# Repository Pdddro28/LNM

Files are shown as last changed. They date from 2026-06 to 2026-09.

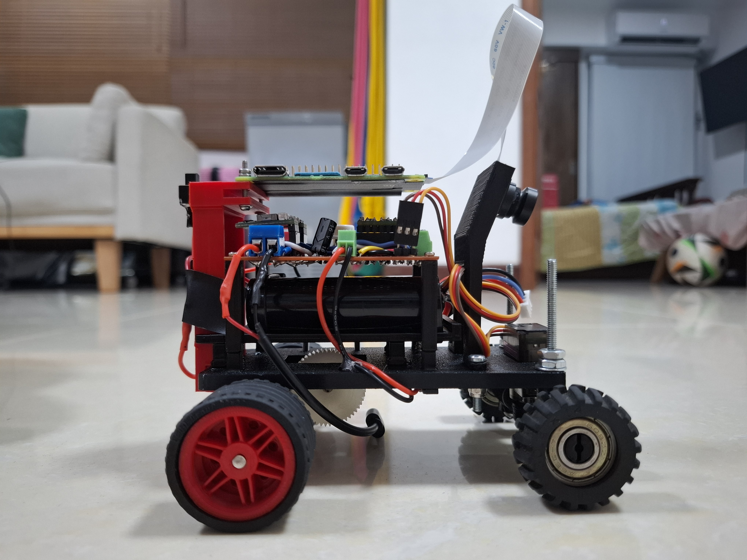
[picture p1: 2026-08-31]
v-photos/Right-view.jpg

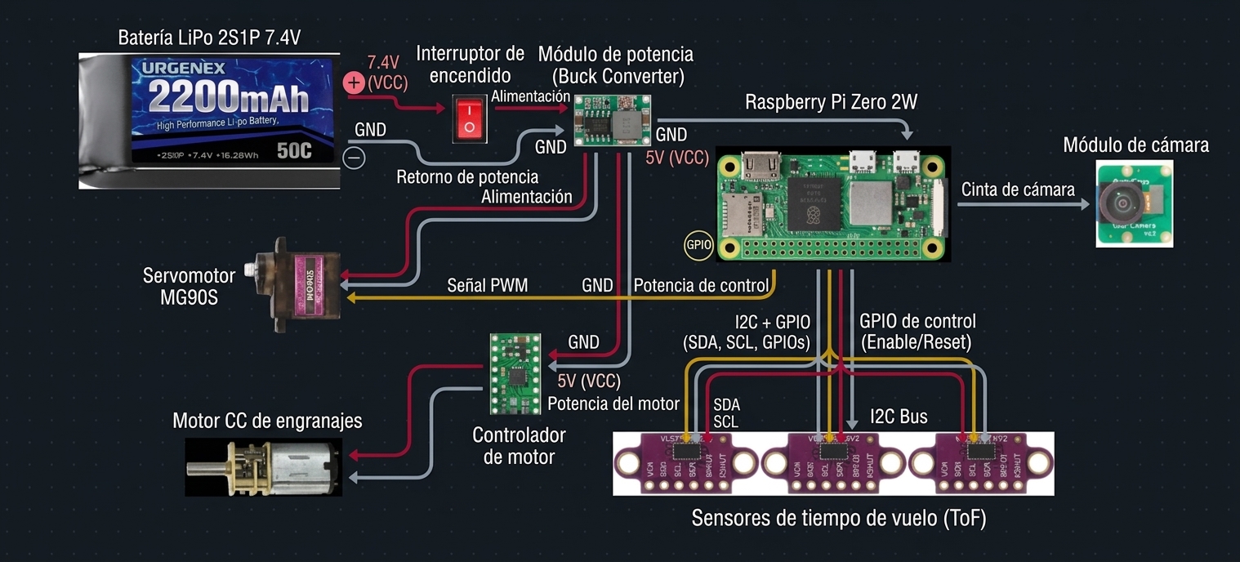
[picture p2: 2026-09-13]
schemes/diagrama_de_cableado.png

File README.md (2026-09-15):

**If you want to see this repository in English, [click here](https://github.com/Pdddro28/K-O-M-R-A-D/blob/main/README_EN.md)**

``` Para mejor visualización, se recomienda ver el repositorio en la computadora ```

# WRO 2026 Future Engineers – LNM

<div align="center">
	
<img width="1000" height="600" alt="WhatsApp Image 2026-06-19 at 11 51 57 PM" src="https://github.com/user-attachments/assets/cee364df-eeba-4338-8f2a-14949adb755b" />

</div>

## **Índice**

1. **[Introducción](#1-introduccion)**
   - 1.1. **[Miembros y Coach](#11-miembros-y-coach)**
      - 1.1.1. **[David Wang](#111-David)**
      - 1.1.2. **[Pedro Catámo](#112-Pedro)**
2. **[Proyectos anteriores](#2-proyectos-anteriores)**
3. **[Diseño y mobilidad](#3-diseño-y-mobilidad)**
   - 3.1. **[Fotos del vehiculo](#31-fotos-del-vehiculo)**
   - 3.2. **[Especificaciones del vehiculo](#32-especificaciones-del-vehiculo)**
   - 3.3. **[Mecanismo ackermann](#33-mecanismo-ackermann)**
   - 3.4. **[Tracción trasera](#34-tracción-trasera)**
   - 3.5. **[Partes 3D, proceso de desarollo y recomendaciones](#35-partes-3d-proceso-de-desarollo-y-recomendaciones)**
4. **[Componentes](#4-componentes)**
   - 4.1. **[Disposicion y justificacion](#41-disposicion-y-justificacion)**
5. **[Presupuesto de energia](#5-presupuesto-de-energia)**
   - 5.1. **[Diagrama de cableado](#51-diagrama-de-cableado)**
6. **[Software](#6-software)**
   - 6.1. **[Herramientas de apoyo](#61-herramientas-de-apoyo)**
   - 6.2. **[Intalación en shell](#62-instalacion-en-shell)**
   - 6.3. **[Compilación y ejecución de archivos(codigos del carro)](#63-compilacion-y-ejecucion)**
   - 6.4. **[Abreviaciones con bash](#64-abreviaciones-con-bash)**
   - 6.5. **[Megapi controller(Deprecated)](#65-megapi-controllerdeprecated)**
   - 6.6. **[Challenge Overview](#66-challenge-overview)**
      - 6.6.1 **[Open Challenge](#661-open-challenge)**
      - 6.6.2 **[Obstacle Challenge](#662-obstacle-challenge)**
      - 6.6.3. **[Estrategia en Ronda Abierta](#663-ronda-abierta-estrategia)**
      - 6.6.4. **[Estrategia en Ronda de Obstáculos](#664-ronda-de-obstaculos-estrategia)**
7. **[Problemas y soluciones durante el desarollo](#7-problemas-y-soluciones-durante-el-desarollo)**
8. **[Licencia y réplica](#8-licencia-y-replicacion)**

---

## 1. Introducción 

Bienvenidos al repositorio de GitHub del **Equipo LNM**, anteriormente conocido como Ars Machina, que compite en la categoría **World Robot Olympiad™ (WRO®) Future Engineers 2026**. Nuestro equipo ha diseñado un vehículo autónomo compacto e innovador para hacer frente a los retos dinámicos de la competición WRO 2026.

Esta es la estructura general de carpetas de nuestro repositorio:

<div align="center">
	
| Carpeta | Contenido técnico | Documentación detallada |
|---|---|---|
| **models** | **Diseños 3D**<br>• Piezas del carro| [Explora los modelos 3D](models/README.md) |
| **schemes** | **Sistemas eléctricos**<br>• Diagramas de cableado<br>• Gestión de la alimentación<br>• Esquemas de componentes| [Explora la documentación de esquemas y cableado](schemes/README.md) |
| **src** | **Algoritmos de software**<br>• Lógica de navegación<br>• Fusión de sensores<br>• Sistemas de control | [Explora la documentación de software y algoritmos](src/README.md) |
| **t-photos** | **Documentación del equipo**<br>• Perfiles de los miembros | [Explora la documentación de fotos del equipo](t-photos/README.md) |
| **v-photos** | **Documentación del vehículo**<br>• Vistas desde múltiples ángulos | [Explora la documentación de fotos del vehículo](v-photos/README.md) |
| **video** | **Validación del rendimiento**<br>• Demostraciones del desafío<br>• Pruebas de ingeniería | [Explora la documentación de los vídeos de rendimiento](video/README.md) |

</div>

### 1.1. Miembros y Coach 

<div align="center">
	
<img width="1280" height="720" alt="Team_pic (1)" src="https://github.com/user-attachments/assets/156c3c29-799e-44e6-a7f0-629da61873b8" />

</div>

<div align="center">

| **Miembro** | **Miembro** | **Coach** |
| :---: | :---: | :---: |
| 👤 **David Wang** | 👤 **Pedro Catamo** | 👤 **Jesús Alcalá** |
| 📅 **Nacido en:** 04/01/2011 (15 años)<br>🏫 **Estudio:** 4º año en la U.E.C. Eduardo Blanco<br>📧 **Gmail:** [davidwangwu104@gmail.com](mailto:davidwangwu104@gmail.com) | 📅 **Nacido en:** 28/01/2009 (17 años)<br>🏫 **Estudio:** Graduado en la U.E.C. Colegio Eduado Blanco<br>📧 **Gmail:** [pedrocatamo.2009@gmail.com](mailto:pedrocatamo.2009@gmail.com) | 📅 **Nacido en:** 18/11/2005 (21 años) <br> 🏫 **Estudio:** Ingenieria en computación & Ingenieria informática <br> 📧 **Gmail:** [Jdam50002@gmail.com](mailto:Jdam50002@gmail.com) |

</div>

---

#### 1.1.1. David Wang 

**Rol: Programación y Lógica Autónoma, Integrador de Sistemas y  Diseñador 3D**

<div align="center">

<img width="400" height="700" alt="David" src="https://github.com/user-attachments/assets/f19589c0-22ea-44fb-ba63-21a8cb10d5f8" />

</div>

* **Programación y Lógica Autónoma:** Me encargo del desarrollo del código en la placa pprincipal, la lógica de control del vehículo y la programación del sistema de visión por computadora.

* **Integración de Sistemas:** Me aseguro de que la información de la cámara se traduzca correctamente en movimientos del vehículo de forma fluida.

* **Diseñador 3D:** Trabajo en la conceptualización y modelado CAD del chasis y las piezas junto al mentor del área técnica, adaptando la estructura según las necesidades del espacio que requiere la electrónica.

#### 1.1.2. Pedro Catámo 

**Rol: Ensamblaje Mecánico y Mantenimiento, Ingeniería de Pruebas y Telemetría y Redacción y Gestión del Reporte Técnico**

* **Ensamblaje Mecánico y Mantenimiento:** Me encargo del montaje físico del carro, el ajuste de tornillería, la calibración de componentes con herramientas de precisión y la revisión del estado general del vehículo para evitar fallos físicos.

* **Ingeniería de Pruebas y Telemetría:** Registro los tiempos en pista, mide el rendimiento del carro en cada intento y anota qué ajustes físicos o de parámetros generan mejoras o fallos.

* **Redacción y Gestión del Reporte Técnico:** Responsable principal de estructurar y maquetar el documento del proyecto que se entrega a los jueces, recopilando la información del código, el diseño y las pruebas.

#### 1.1.3. Jesús Alcalá 

**Rol: Mentor de Programación y Lógica, Mentor de Diseño y Estructura y Mentor de Gestión y Reglamento**

<div align="center">

<img width="500" height="700" alt="1000281781" src="https://github.com/user-attachments/assets/f77cb86f-cff0-4f8c-8ea1-c10f3c5291b0" />

</div>

* **Mentor de Programación y Lógica:** Me encargo de guiarlos en la arquitectura del código, la lógica de navegación autónoma y el procesamiento de imágenes. Los oriento en la resolución de errores lógicos y en la optimización del programa para garantizar un rendimiento estable en pista.

* **Mentor de Diseño y Estructura:** Me encargo de guiarlos en la concepción física del vehículo, enseñándoles técnicas de diseño CAD y optimización de piezas para lograr un chasis resistente y funcional.

* **Mentor de Gestión y Reglamento:** Encargado de verificar el cumplimiento estricto del reglamento de la WRO, asesorarlos en la estructuración de la documentación técnica y orientarlos en las decisiones generales del proyecto para asegurar un desarrollo ordenado.

---

## 2. Proyectos anteriores 

<div align="center">
	
| Foto | Nombre | Descripción |
|---|---|---|
| <img width="5000" height="5000" alt="Captura de pantalla 2026-06-17 185504" src="https://github.com/user-attachments/assets/36166165-a542-42d6-a771-41a60693a399" /> | **Cyber Cooper** | En 2023 teníamos pensado diseñar el coche desde cero, modelando e imprimiendo nuestras propias piezas en 3D, incluidos el chasis y el sistema de dirección. Aunque al principio parecía una buena idea, a medida que avanzábamos empezamos a encontrarnos con un problema tras otro, y nos dimos cuenta de que nuestro diseño actual nos acarrearía más dificultades. Al final, hicimos todo lo que pudimos dentro de las limitaciones de tiempo que teníamos. |
| <img width="5000" height="5000" alt="front2" src="https://github.com/user-attachments/assets/ce130237-cc0b-4aa9-a620-0aea287408c2" /> | **Cooper** | En 2024 desarrollamos un chasis con piezas 3D estructurado en dos niveles. El nivel inferior albergaba los sensores y la electrónica de bajo nivel, mientras que el superior sostenía las baterías y la Raspberry Pi 3 para optimizar el espacio. Aunque logramos un gran avance estético y funcional, sufrimos lecciones duras en pista: el peso excesivo provocó la flexión de los acoples en la transmisión trasera, lo cual, a su vez, generó problemas severos de fricción mecánica entre las piezas impresas en 3D. |
| <img width="5000" height="5000" alt="front" src="https://github.com/user-attachments/assets/804b3d7f-3500-4351-a917-ccf781029804" /> | **Halbi** | En 2025 teniendo en cuenta los recursos de los que disponíamos en ese momento, nuestra idea principal era rediseñar el Cybercooper, modificando la base y la estrategia existentes y utilizando mejores componentes electrónicos; empezamos a imprimir las nuevas piezas con material blanco y a pensar en mejores formas de montar el sistema de dirección del coche. Al final, decidimos utilizar una base prefabricada para el chasis; la razón principal fue ahorrar tiempo (y dolores de cabeza) con el diseño mecánico, lo que nos permitía dedicar más tiempo a la electrónica y la programación. |
| <img width="5000" height="5000" alt="WhatsApp Image 2026-06-18 at 7 39 40 PM" src="https://github.com/user-attachments/assets/ca9f62ff-7b8b-452a-97de-95ebf12dc0ef" /> | **The Fridge** | En 2025 a diferencia de los modelos anteriores que pertenecían a nuestro coach, "The Fridge" fue un diseño construido enteramente por nosotros. Aquí dimos el salto a la geometría Ackermann e imprimimos la gran mayoría de las piezas en 3D. A nivel motriz, usamos un motor DC con un engranaje acoplado para traccionar ambas ruedas. Físicamente le instalamos 3 sensores ultrasónicos, una Raspberry Pi 4 y un giroscopio MPU6050, pero por falta de tiempo y severos problemas de configuración, la Raspberry y el IMU quedaron como peso muerto y terminamos controlando todo únicamente desde la MegaPi. Sufrimos muchísimo: las piezas de la dirección impresas en 3D se rompían constantemente por el estrés, y programar la navegación autónoma en Arduino dependiendo de puros rebotes ultrasónicos fue casi imposible. Siendo sinceros, terminó siendo el peor proyecto de los tres. |
| <img width="5000" height="5000" alt="604735892-f1dc12a1-dbfc-46f3-9a21-a679aa1aa3db" src="https://github.com/user-attachments/assets/2101e66c-5b43-4e2d-938d-b143c6c9f9ed" /> | **Halbi The Green** | Este es el primer modelo que hemos fabricamos como LNM, siendo el carro con el cual competimos en las primeras regionales de WRO Venezuela 2026, este lograba realizar la ronda abierta de manera perfecta en un tiempo de alrededor de 20seg pero a la hora de la ronda de obstaculos este se veia frenado por diversas limitaciones tales como; Su tamaño debido a que el ancho de este le dificultaba atravesar los obstaculos de manera precisa, limitaciones del sistema de direccion el cual no podia realizar giros cerrados, otra de las dificultades que se presentaron fue que algunos de los cables del robot y sensores de los laterales tumbaban los obstaculos de manera ocacional, en resumen el principal problema de Halbi The Green fue su tamaño y su incapacidad de hacer giros cerrados. |

</div>

---

## 3. Diseño y mobilidad 

A continuación se detalla la construcción y funcionamiento dinámico de nuestro robot **Halbi The Green**:

### 3.1. Fotos del vehiculo 

<div align="center">

| | **Diferentes ángulos del carro** | |
|---|---|---|
| **Superior** | **Derecha** | **Izquierda** |
| <img width="2000" height="2000" alt="Upper-view" src="https://github.com/user-attachments/assets/2a0562c0-60e4-4d0a-a93d-6cc70a388efa" /> | <img width="2000" height="2000" alt="Right-view" src="https://github.com/user-attachments/assets/336adf6b-3f85-432b-8a5c-26227200b8f9" /> | <img width="2000" height="2000" alt="Left-view" src="https://github.com/user-attachments/assets/d6df94f0-d30b-46f6-812e-c9d6f7930e63" /> |
|**Frontal** | **Trasera** | **Inferior** |
| <img width="2000" height="2000" alt="Front-view" src="https://github.com/user-attachments/assets/ef03746f-1543-4490-8521-824d5e7d0d57" /> | <img width="2000" height="2000" alt="Back-view" src="https://github.com/user-attachments/assets/150ab54f-12d3-4e58-a0bc-a9be14865f2c" /> | <img width="2000" height="2000" alt="Bottom-view" src="https://github.com/user-attachments/assets/a253c009-53f8-4fcc-a485-942bfddd27fd" /> |

</div>

### 3.2. Especificaciones del vehiculo 

* **Dimensiones totales:** 14 cm (largo) × 12 cm (ancho) × 10.3 cm (alto).
* **Peso del carro:** aproximadamente 346g.
* **Sistema de tracción:** Tracción Trasera Mecánica Bifásica.
* **Sistema de dirección:** Geometría Ackermann.

### 3.3. Mecanismo ackermann 

El vehículo utiliza una geometría precisa basada en el **Principio de Dirección Ackermann** para conquistar curvas cerradas con cero deslizamiento lateral y un desgaste mínimo de los neumáticos.

* **La Física Detrás del Principio:** Cuando un vehículo entra en una curva, la rueda delantera interior sigue un radio concéntrico más cerrado y pequeño que la rueda exterior. Si ambas ruedas giraran exactamente al mismo ángulo, los neumáticos lucharían entre sí, provocando que el neumático exterior se arrastre, pierda agarre mecánico e introduzca vibraciones estructurales severas que arruinarían el seguimiento visual de los carriles. Para resolver esto, la geometría mecánica obliga a la rueda interior a pivotar a un ángulo más profundo que la rueda exterior, asegurando que las cuatro ruedas roten alrededor de un único centro instantáneo de curvatura (ICC) común.

* **La Ejecución Mecánica:** Un servo digital **MG996R** de alto par ($11 \text{ kg}\cdot\text{cm}$ de par) se ancla al mamparo delantero mediante un soporte de aluminio en forma de L mecanizado a medida para eliminar la deflexión estructural. El brazo del servo acciona una cremallera de dirección de doble enlace conectada a tirantes asimétricos y manguetas de dirección. Los brazos de dirección están angulados hacia el interior, apuntando al centro del eje trasero, completando el clásico "Trapezoide de Ackermann". Este diseño mecánico exacto convierte el desplazamiento lineal del servo en ángulos de rueda no lineales de forma automática.

* **El Control Digital y Calibración:** El MG996R es controlado por un tren de pulsos PWM por hardware continuo y libre de fluctuaciones (*jitter*) a $50\text{Hz}$ directamente desde el microcontrolador MegaPi. La dirección está rígidamente mapeada y calibrada a una banda muerta de software donde los $80^\circ$ representan el centro geométrico absoluto. Los puntos finales mecánicos están limitados por software entre $40^\circ$ (Máximo Izquierda) y $105^\circ$ (Máximo Derecha) para evitar que los eslabones de la dirección alcancen un bloqueo mecánico o fuercen los límites de pérdida del motor.

<div align="center">

<img width="1300" height="600" alt="Ackerman" src="https://github.com/user-attachments/assets/b7252526-1fb0-4340-9039-a15a9050c84f" />

</div>

#### Entendiendo la Matemática y Cinemática Ackermann

En robótica móvil tradicional (como los robots de la categoría *RoboMission*), se utiliza la tracción diferencial porque es matemáticamente simple: varías la velocidad de dos motores y el robot gira sobre su propio eje. Sin embargo, a altas velocidades, la tracción diferencial es inestable e impredecible.

**La Geometría Ackermann** resuelve esto mediante un principio puramente mecánico. Para que un vehículo gire sin deslizarse lateralmente, las líneas extendidas desde los ejes de todas las ruedas deben cruzarse en un único punto en el espacio: el **Centro Instantáneo de Rotación (CIR)** o ICC.

La ecuación matemática fundamental que gobierna esta cinemática es:
<div align="center">

$$\cot(\theta_{\text{out}}) - \cot(\theta_{\text{in}}) = \frac{w}{L}$$

</div>

Donde:
* $\theta_{\text{in}}$ es el ángulo de giro de la rueda interna.
* $\theta_{\text{out}}$ es el ángulo de giro de la rueda externa.
* $w$ es el ancho de la vía (*track width* o distancia entre las ruedas frontales).
* $L$ es la batalla del carro (*wheelbase* o distancia entre el eje delantero y trasero).

Dado que la cotangente crece más rápido a ángulos pequeños, esta relación obliga mecánicamente a que $\theta_{\text{in}} > \theta_{\text{out}}$ de forma automática en cualquier curva, abriendo el ángulo de la rueda exterior para que dibuje un círculo más grande.

<div align="center">

<img width="700" height="700" alt="ackermann png" src="https://github.com/user-attachments/assets/4d664a20-9be0-47e3-a76d-9321eebc615a" />

</div>

### 3.4. Tracción trasera 

La fuerza motriz de la plataforma se genera mediante un sistema de tracción trasera (2WD) de alto rendimiento, el cual rompe con los esquemas tradicionales de acoplamiento directo al integrar una transmisión mecánica desmultiplicada de dos velocidades por engranajes cilíndricos rectos.

* **Arquitectura del Sistema de Transmisión:** A diferencia de las configuraciones comunes que acoplan la rueda directamente a la caja reductora del motor, este diseño monta el motor N20 en una disposición paralela superior sobre un bloque de soporte rígido. La potencia se transfiere desde el eje primario del motor hacia un eje secundario de tracción inferior mediante un tren de engranajes expuesto con dentado recto. Este sistema de dos velocidades mecánicas intercambiables permite configurar el robot según las exigencias de la pista:
  1. **Relación de Fuerza/Torque (Primera Velocidad):** Optimiza el desmultiplique para obtener la máxima aceleración y un control milimétrico en curvas cerradas u obstáculos, ideal para tramos revirados. 
  2. **Relación de Velocidad Final (Segunda Velocidad):** Reduce la pérdida de revoluciones para aprovechar la inercia lineal en rectas largas, garantizando una alta velocidad de crucero sin saturar el consumo eléctrico.
  3. **Modificación al sistema de transmisión(cambio al eje y ruedas):** Habian limitaciones a la hora de girar a angulos mas cerrados con ambas ruedas fijas al motor, esto causaba un deslizamiento/derrape en el momento en el cual el carro giraba, debido a estos contratiempos se contemplaron 2 cambios posibles, cambiar la transmision acual por un sistema diferencial para que la velocidad de las ruedas se adecuaran al giro, o dejar una de las ruedas fija al eje del motor y la otra que girara libre, asi simulando uno de los efectos del diferencial, nos terminamos decantando por la 2da opcion la cual era mas rapida de implementar y termino funcionando bastante bien logrando que el carro pudiera girar mucho mejor.

<div align="center">

<img width="800" height="500" alt="Sistema de transmision de 2 velocidades K-O-M-R-A-D" src="https://github.com/user-attachments/assets/da8175e6-313d-42d6-bd3b-b1318082536f" />

</div>

## *Una demostración de la tracción trasera*

<div align="center">

https://github.com/user-attachments/assets/042841d2-482d-409c-a0ef-2fa391119745

</div>

# Especificaciones Técnicas y Análisis Cinemático del Vehículo

## a. Especificaciones Técnicas de los Motores (N20 - 100 RPM)

El sistema de propulsión posterior del vehículo confía en micro-motoreductores de CC con escobillas metálicas (tipo N20) integrados con una caja reductora de engranajes metálicos rectos. Este conjunto fue seleccionado específicamente para optimizar la relación torque/volumen dentro de las dimensiones compactas del chasis ($14\text{ cm} \text{ (largo)} \times 12\text{ cm} \text{ (ancho)} \times 10.3\text{ cm} \text{ (alto)}$) y gestionar eficientemente la inercia asociada a su masa total de aproximadamente $346\text{ g}$.

* **Voltaje Nominal de Operación:** Operando a un voltaje nominal de $6\text{V}$ (ajustado mediante la etapa de potencia desde la fuente principal). Su comportamiento térmico y eléctrico se mantiene estable bajo periodos prolongados de tracción activa.
* **Corriente de Vacío (No-load):** $\approx 0.06\text{ A} - 0.08\text{ A}$ por motor.
* **Corriente de Bloqueo / Arranque (Stall):** $\approx 0.7\text{ A} - 0.8\text{ A}$ a $6\text{V}$. Esta demanda pico encaja de manera óptima dentro de las especificaciones del driver **DRV8833**, el cual soporta hasta $1.2\text{ A}$ de corriente continua por canal ($2.0\text{ A}$ pico), garantizando un margen térmico y de corriente seguro ante caídas de velocidad o eventuales atascamientos en pista.
* **Velocidad de Rotación de Salida:** $100\text{ RPM}$ en el eje D de la caja reductora a voltaje nominal.
* **Torque Nominal y de Bloqueo:** Entrega aproximadamente $0.8\text{ kg}\cdot\text{cm} - 1.2\text{ kg}\cdot\text{cm}$ de torque de bloqueo, suficiente para romper la fricción estática de la masa de $346\text{ g}$ sin provocar un deslizamiento excesivo o pérdida de tracción en las ruedas motrices traseras.

### Motor N20
<div align="center">
<img width="500" height="202" alt="D_NQ_NP_927109-MLV78777179998_092024-O" src="https://github.com/user-attachments/assets/893776fb-e058-4613-ada9-9e5b64286ebd" />
</div>

## b. Análisis Cinemático y Cálculo de la Velocidad Teórica Absoluta

Para modelar la dinámica del vehículo en pista y calibrar las ventanas de tiempo por vuelta (como el parámetro de control `lap_time = 4.3`), se realiza un análisis cinemático directo enfocado exclusivamente en el eje trasero motriz (**Tracción Trasera Mecánica Bifásica**) e interactuando dinámicamente con la **Geometría de Dirección Ackermann** ubicada en el eje delantero.

### c. Cálculo de Perímetro y Velocidad Lineal Teórica ($V_{max}$)

Considerando un diámetro de rueda trasera de $D = 6.5\text{ cm} = 0.065\text{ m}$:

c1. **Circunferencia de Rodadura ($C$):**
   $$C = \pi \cdot D = \pi \cdot 0.065\text{ m} \approx 0.2042\text{ m/vuelta}$$

c2. **Frecuencia de Rotación ($\omega$):**
   $$N = 100\text{ RPM} \implies n = \frac{100}{60} \approx 1.667\text{ rev/s}$$

c3. **Velocidad Lineal Máxima Teórica ($V_{teorica}$):**
   $$V_{teorica} = C \cdot n = 0.2042\text{ m} \times 1.667\text{ s}^{-1} \approx 0.340\text{ m/s} \quad (34.0\text{ cm/s})$$

### d. Interacción Cinemática: Tracción Trasera y Dirección Ackermann

* **Control con Driver DRV8833:** El puente en H dual DRV8833 modula por PWM la tensión aplicada a los dos motores N20 independientes situados en el eje posterior. Al no contar con un diferencial mecánico físico en el eje trasero, el control electrónico puede ajustar sutilmente la velocidad diferencial entre ambas ruedas traseras para prevenir el arrastre o patinaje durante las curvas.
* **Geometría Ackermann en el Eje Delantero:** Las ruedas delanteras (no motrices) pivotan en ángulos desiguales ($\theta_{interna} > \theta_{externa}$) para converger en un centro instantáneo de rotación único (Punto ICC). Esto elimina el deslice lateral de las llantas de guía, garantizando que la velocidad lineal impulsada por los motores N20 ($0.340\text{ m/s}$) se transfiera eficientemente en trayectoria tangencial sobre las curvas.
* **Distribución de Masa e Inercia:** Con una masa total de $m = 346\text{ g}$, la fricción estática del eje trasero genera la fuerza de adherencia ($F_N = m_{trasera} \cdot g$) adecuada para transformar el torque del N20 en aceleración longitudinal instantánea, minimizando pérdidas cinéticas por patinaje inicial.

<div align="center">

$$C = \pi \times 0.065\text{ m} \approx 0.2041\text{ m}$$

</div>

Transformando las revoluciones por minuto del eje secundario de la transmisión a revoluciones por segundo y multiplicando por el desarrollo de la circunferencia, obtenemos la velocidad de avance del chasis:

<div align="center">

$$V = \frac{450\text{ RPM}}{60} \times 0.2041\text{ m} \approx 1.53\text{ m/s}$$

</div>

Este valor de $1.53\text{ m/s}$ representa la velocidad límite ideal de la plataforma. En condiciones reales de competencia, este vector se modula por software mediante los comandos de velocidad (`speed = 90` u `80`) para absorber la fricción estática del suelo, la resistencia al avance de los rodamientos y las demandas instantáneas de corriente solicitadas por la MegaPi al gestionar el cambio de inercias.

### 3.5. Partes 3D, proceso de desarollo y recomendaciones 

#### **Piezas impresas:**

## **Actualmente en uso:**

<div align="center">

| Component & Preview | Design & Geometry | Engineering Purpose |
|---|---|---|
| **Base** <br><br><img width="5000" height="5000" alt="Screenshot 2026-08-31 202443" src="https://github.com/user-attachments/assets/a43d8427-49c6-4ba9-b476-d3507ed1c122" /> | Diseñado como una jaula de torre vertical estructurada con cuatro pilares reforzados en cada lado, integrada directamente sobre una base de montaje sólida con ojales para tornillos en las esquinas. Las paredes laterales cuentan con grandes recortes circulares para minimizar el peso del material mientras permiten un flujo de aire pasivo máximo para evitar el estrés térmico en las celdas LiPo durante altas tasas de descarga. El pilar superior incluye ojales de retención ranurados para una sujeción segura de las correas. | Centraliza la masa combinada de las celdas de la batería verticalmente a lo largo del eje geométrico central del chasis. Este diseño de jaula abierta garantiza un acceso rápido para el reemplazo de la batería entre carreras, al tiempo que proporciona una contención estructural rígida contra las fuerzas de inercia laterales durante giros a alta velocidad. |
| **Camera Case** <br><br><br><br><img width="5000" height="5000" alt="Screenshot 2026-09-07 215051" src="https://github.com/user-attachments/assets/0c08317a-1e44-4cd3-bab9-131de38c4b43" /> | Una carcasa protectora rectangular y compacta, diseñada específicamente para encapsular el sensor IMX219 (Arducam). Esta es la base de la camara, es una base de angulo fijo y elevada a la altura del robot | Esta se decidio dejar con un angulo fijo debido a que a lo largo del uso del 1er prototipo de carro para FE 2026 ("Halbi the green") nos dimos cuenta que ese era el angulo que mejor nos funcionaba para visualizar la pista desde el punto de vista del robot. |
| **Battery Case Holder** <br><br><img width="5000" height="5000" alt="Screenshot 2026-08-31 202626" src="https://github.com/user-attachments/assets/fb8e684a-ccae-4751-a0b8-2ddd3868f73f" /> | Una bandeja robusta de perfil bajo equipada con cuatro soportes verticales integrados de alta resistencia posicionados en las esquinas para asegurar el PCB principal. La placa base cuenta con guías de distribución internas y cortes de holgura estructural para evitar los componentes en la parte inferior de la placa, manteniendo el perfil lo más cercano posible al chasis. | Funciona como una cuna mecánica rígida para la electrónica de potencia de bajo nivel. Al elevar el PCB mediante los soportes integrados de 3 mm, evita cortocircuitos eléctricos con el chasis al tiempo que amortigua las vibraciones. El perímetro completamente abierto garantiza el acceso inmediato a los terminales de tornillo del motor, los rieles de alimentación y los puertos de sensores para el mantenimiento en campo. |
| **Rim** <br><br><img width="5000" height="5000" alt="Screenshot 2026-08-31 202820" src="https://github.com/user-attachments/assets/a630e90b-b8e5-4b55-93bc-9aa0c6145042" /> | Una plataforma modular plana de nivel medio que cuenta con cuatro soportes de esquina integrados para montar la Raspberry Pi 4 de forma segura. La sección frontal de la base integra un montaje de bisagra de doble oreja equipado con dientes de bloqueo internos que se acoplan directamente con la bisagra de la carcasa de la cámara (Camera Case). | Sirve como un puente estructural de doble propósito. Proporciona un montaje estable y elevado para la computadora de a bordo de alto nivel, asegurando una disipación óptima del calor a través de la convección natural para evitar el estrangulamiento térmico del CPU. Al mismo tiempo, su montaje engranado integrado bloquea firmemente el ensamblaje de la cámara en la parte delantera, eliminando la necesidad de componentes adicionales y ahorrando valioso espacio en el chasis.|
| **Motor DC Case** <br><br><img width="5000" height="5000" alt="Screenshot 2026-08-31 202852" src="https://github.com/user-attachments/assets/6c1eb648-30fb-4358-abad-df5134edbd21" /> | Un soporte protector compacto de doble barril hecho a medida para encapsular firmemente los cilindros del transmisor y receptor del módulo del sensor ultrasónico. Cuenta con pestañas de montaje traseras integradas y bridas inferiores para un acoplamiento mecánico continuo a las vigas transversales delanteras de la estructura del chasis. | Proporciona una carcasa rígida y aislada de vibraciones que mantiene el sensor ultrasónico perfectamente perpendicular al plano horizontal de la pista. Esta alineación precisa elimina la distorsión de la señal acústica y la dispersión de las ondas, garantizando mediciones de distancia en tiempo real altamente precisas para la detección de obstáculos y mapas de frenado de emergencia. |
| **Direccional** <br><br><img width="5000" height="5000" alt="Screenshot 2026-08-31 202722" src="https://github.com/user-attachments/assets/6c66220a-595f-4e60-8dd9-857fee6638fa" /> | Un soporte protector compacto de doble barril hecho a medida para encapsular firmemente los cilindros del transmisor y receptor del módulo del sensor ultrasónico. Cuenta con pestañas de montaje traseras integradas y bridas inferiores para un acoplamiento mecánico continuo a las vigas transversales delanteras de la estructura del chasis. | Proporciona una carcasa rígida y aislada de vibraciones que mantiene el sensor ultrasónico perfectamente perpendicular al plano horizontal de la pista. Esta alineación precisa elimina la distorsión de la señal acústica y la dispersión de las ondas, garantizando mediciones de distancia en tiempo real altamente precisas para la detección de obstáculos y mapas de frenado de emergencia. |
| **Triangulo Ackermann** <br><br><img width="5000" height="5000" alt="Screenshot 2026-08-31 202522" src="https://github.com/user-attachments/assets/32e2294f-8eb8-408a-979d-4f841066f1c7" /> | Un soporte protector compacto de doble barril hecho a medida para encapsular firmemente los cilindros del transmisor y receptor del módulo del sensor ultrasónico. Cuenta con pestañas de montaje traseras integradas y bridas inferiores para un acoplamiento mecánico continuo a las vigas transversales delanteras de la estructura del chasis. | Proporciona una carcasa rígida y aislada de vibraciones que mantiene el sensor ultrasónico perfectamente perpendicular al plano horizontal de la pista. Esta alineación precisa elimina la distorsión de la señal acústica y la dispersión de las ondas, garantizando mediciones de distancia en tiempo real altamente precisas para la detección de obstáculos y mapas de frenado de emergencia. |
| **Pillar** <br><br><img width="5000" height="5000" alt="Screenshot 2026-08-31 202741" src="https://github.com/user-attachments/assets/3de1f1a2-ce3a-4e5d-aaff-baba42a604d2" /> | Un soporte protector compacto de doble barril hecho a medida para encapsular firmemente los cilindros del transmisor y receptor del módulo del sensor ultrasónico. Cuenta con pestañas de montaje traseras integradas y bridas inferiores para un acoplamiento mecánico continuo a las vigas transversales delanteras de la estructura del chasis. | Proporciona una carcasa rígida y aislada de vibraciones que mantiene el sensor ultrasónico perfectamente perpendicular al plano horizontal de la pista. Esta alineación precisa elimina la distorsión de la señal acústica y la dispersión de las ondas, garantizando mediciones de distancia en tiempo real altamente precisas para la detección de obstáculos y mapas de frenado de emergencia. |

</div>

###**Control de versiones**

##Estos son todos los modelos empleados a lo largo del uso del carro

<div align="center">

| Archivo | Categoría / Subsistema | Tipo | Estado / Versión | Registro de Cambios / Notas |
| --- | --- | --- | --- | --- |
| **Chasis Ing_01.stl** | Estructura / Chasis | Modelo 3D | v1.0 | Versión inicial del módulo de chasis(actual) <img width="60" height="60" alt="image" src="https://github.com/user-attachments/assets/0a52fc2e-f24b-4e39-b533-8d27122c9fff" />|
| **Chasis Ing_02.stl** | Estructura / Chasis | Modelo 3D | v1.1 | Ajuste y modificacion de encages(actual) <img width="60" height="60" alt="chassis 2" src="https://github.com/user-attachments/assets/87dbbc7e-e684-4b3e-a303-eff6fd0788c4" />|
| **Chasis Ing_03.stl** | Estructura / Chasis | Modelo 3D | v1.2 | Modificación de puntos de fijación(actual) <img width="60" height="60" alt="chassis 3" src="https://github.com/user-attachments/assets/040432da-a6a5-4295-b2bc-ebe392392554" />|
| **Chasis Ing_04.stl** | Estructura / Chasis | Modelo 3D | v1.3 | Optimización de grosor de pared(actual) <img width="60" height="60" alt="chassis 4" src="https://github.com/user-attachments/assets/dbc39911-a64c-4891-bc1d-e53381995408" />|
| **Chasis Ing_05.stl** | Estructura / Chasis | Modelo 3D | v1.4 | adicion de espacio para la traccion(actual) <img width="60" height="60" alt="chassis 5" src="https://github.com/user-attachments/assets/27fd48cd-7148-4b0a-8776-85946bd72d4a" />|
| **Chasis Ing_06.stl** | **Estructura / Chasis** | Modelo 3D | v1.5 | Reorganización de huecos para cables(actual) <img width="60" height="60" alt="chassis 6" src="https://github.com/user-attachments/assets/cdb0ac6e-ac42-45cc-8e68-d5e27928e12d" />|
| **Chasis Ing_07.stl** | Estructura / Chasis | Modelo 3D | v1.6 | Ensanche de el hueco central(actual) <img width="60" height="60" alt="chassis 7" src="https://github.com/user-attachments/assets/f0e23bdd-37eb-4dc7-baba-f2ff393334ec"/>|
| **LNM_FI.stl** | Estructura / Chasis | Modelo 3D | v1.0 | modelo chassis completo(deprecated) |
| **ing akerman .stl** | Dirección y Transmisión | Modelo 3D | v1.0 | Diseño base del sistema Ackermann |
| **ing akerman 1.stl** | Dirección y Transmisión | Modelo 3D | v1.1 | Revisión de ángulo de giro |
| **ing akerman 2.stl** | Dirección y Transmisión | Modelo 3D | v1.2 | Ajuste de orificio para pasador |
| **ing akerman 3.stl** | Dirección y Transmisión | Modelo 3D | v1.3 | Refuerzo en el brazo de acople |
| **Ing eje 01.stl** | Dirección y Transmisión | Modelo 3D | v1.0 | Eje de rueda primario para traccion trasera(actual) <img width="60" height="60" alt="eje 1" src="https://github.com/user-attachments/assets/981f13bf-b080-4d76-97d4-357239d5d770" />|
| **Ing eje 02.stl** | Dirección y Transmisión | Modelo 3D | v1.1 | Eje modificado para nueva transmisión(actual)<img width="60" height="60" alt="ing eje 2" src="https://github.com/user-attachments/assets/a8bfbc44-759b-4bb1-9755-8f0bb65ac8ce" />|
| **Ing eje DIF.stl** | Dirección y Transmisión | Modelo 3D | v1.0 | Eje adaptado para diferencial |
| **Ing PIN WHEEL.stl** | Dirección y Transmisión | Modelo 3D | v1.0 | Pasador/pin de sujeción de rueda(actual) <img width="60" height="60" alt="Captura de pantalla 2026-09-14 224225" src="https://github.com/user-attachments/assets/206103a3-b63a-442b-a417-8a236a55d81a" />|
| **Ing SOP NEW EJE .stl** | Dirección y Transmisión | Modelo 3D | v2.0 | Nuevo soporte para el eje principal <img width="60" height="60" alt="sop new eje" src="https://github.com/user-attachments/assets/9e9453fd-ff75-40b3-be99-3931fd7c3e75" />|
| **Ing SOP TOP.stl** | Dirección y Transmisión | Modelo 3D | v1.0 | Soporte superior para raspberry(actual) <img width="60" height="60" alt="Sop top" src="https://github.com/user-attachments/assets/46ec8d18-42b4-4c3b-b542-f827dde9fb76" />|
| **ing BAT SOP.stl** | Soportes y Sujeciones | Modelo 3D | v1.0 | Soporte para la batería 2do piso(actual)<img width="60" height="60" alt="Bat sop" src="https://github.com/user-attachments/assets/d4af1e0a-31d2-4941-8646-7fe7627e51ac" />|
| **ing SERVO ARM.stl** | Soportes y Sujeciones | Modelo 3D | v1.0 | Brazo de acople para servomotor |
| **ing SOP CAM .stl** | Soportes y Sujeciones | Modelo 3D | v1.0 | Soporte para módulo de cámara IMX219(actual)<img width="60" height="60" alt="Sop cam" src="https://github.com/user-attachments/assets/af98f137-4eb2-41fa-b15d-8b1275c05ea4" />|
| **ing tall PIN .stl** | Soportes y Sujeciones | Modelo 3D | v1.0 | Pin/pasador largo de fijación |
| **ing tall PIN 1.stl** | Soportes y Sujeciones | Modelo 3D | v1.1 | Pin largo con tolerancia ajustada |
| **motor clip .stl** | Soportes y Sujeciones | Modelo 3D | v1.0 | Clip de retención para motor |
| **BatteryCase.png** | Documentación / Renders | Render | v1.0 | caja de batería(deprecated) |
| **CameraCase.png** | Documentación / Renders | Render | v1.0 | funda de cámara(deprecated) |
| **MegaPiBase.png** | Documentación / Renders | Render | v1.0 | base MegaPi(deprecated) |
| **RaspberryPiBase.png** | Documentación / Renders | Render | v1.0 | base Raspberry Pi(deprecated) |
| **UltrasonicSensorCase.png** | Documentación / Renders | Render | v1.0 |case del ultrasónico(deprecated) |

</div>

#### Muestra de los modelos del sistema Ackermann:

<img width="1920" height="1080" alt="0001-0100" src="https://github.com/user-attachments/assets/ac5a9cf8-e236-4da2-8057-b28e798af2ff" />

#### Muestra ensamble de componentes 3D:

<img src="https://i.ibb.co/https://ibb.co/FbZJ65Lr.gif" width="500" alt="Demo">

#### **Impresoras utilizadas:**

Se usaron las impresoras Creality Hi y Creality K1:

* **Creality Hi:** Es una de las propuestas más recientes de Creality, diseñada con un fuerte enfoque en competir directamente en el mercado de impresión multicolor accesible.

<div align="center">

<img width="500" height="722" alt="animiertes-gif-von-online-umwandeln-de(26) (1)" src="https://github.com/user-attachments/assets/33c6de91-248b-41bc-90b5-ace911543655" />

</div>

  * **Volumen de construcción:** $260 \times 260 \times 300\text{ mm}$. Es un tamaño intermedio-alto, excelente para robótica porque te permite hacer chasis completos en una sola pieza sin tener que segmentarlos.
  * **Dimensiones de la máquina:** $409 \times 392 \times 477\text{ mm}$ (Peso: $8.75\text{ kg}$).
  * Es una impresora cartesiana de alta velocidad equipada con motores step-servo en los ejes X/Y para evitar la pérdida de pasos. Su gran fuerte es la compatibilidad nativa con el sistema CFS (Creality Filament System), un módulo externo tipo "banco de filamentos" que te permite alternar de forma automatizada hasta 4 colores diferentes (o hasta 16 si encadenas 4 módulos). Su velocidad máxima es de $500\text{ m/s}$ con una aceleración de $12,000\text{ mm/s}^2$ y alcanza los $300^\circ\text{C}$ en la boquilla.
  * **¿Qué tan buena es?**
    * *Puntos Fuertes:* Estructura de aluminio fundido extremadamente rígida, calibración y nivelación 100% automática por sensor de deformación, y detección inteligente de enredos o fin de filamento. Si compras la versión Combo (con el CFS), es una máquina brutal para piezas que necesitan soportes solubles o combinar materiales rígidos y flexibles.
    * *Puntos Débiles:* Al no ser cerrada de fábrica (diseño abierto), imprimir materiales técnicos propensos a contraerse como el ABS o ASA de forma consistente puede ser complicado sin construirle una cabina externa.
  * **¿Se recomienda usarla a futuro?** Sí, totalmente. Al ser una plataforma moderna, cuenta con el soporte de software más actualizado (Creality Print 5.1 / OrcaSlicer) y está diseñada bajo el ecosistema de cambio de filamento automático. Es una excelente inversión a largo plazo para un taller.

* **Creality K1:** Lanzada originalmente como la respuesta directa de Creality a la serie P1 de Bambu Lab, es una máquina de nivel profesional diseñada para velocidad pura y materiales exigentes.

<div align="center">

<img width="500" height="500" alt="K1roof_windows" src="https://github.com/user-attachments/assets/40f5c82b-c552-44e5-88a2-95d0ab9ffcd9" />

</div>
  
  * **Volumen de construcción:** $220 \times 220 \times 250\text{ mm}$. Es un espacio estándar (ligeramente más pequeña que la Creality Hi).
  * **Dimensiones de la máquina:** $355 \times 355 \times 480\text{ mm}$ (Peso: $12.5\text{ kg}$).
  * Utiliza un sistema cinemático CoreXY donde el cabezal se mueve de forma ultraligera en los ejes X/Y usando correas cruzadas, mientras la cama solo baja en el eje Z. Al estar completamente cerrada con paneles de vidrio y acrílico, retiene el calor interno en la cámara de impresión. Alcanza una velocidad de $600\text{ mm/s}$ y una aceleración masiva de $20,000\text{ mm/s}^2$ gracias a su firmware basado en Klipper (Creality OS).
  * **¿Qué tan buena es?**
    * *Puntos Fuertes:* Es una bestia para materiales técnicos. Su cámara cerrada es perfecta para imprimir PETG, ABS, ASA y Nylon sin sufrir warping (despegue de bordes). Su aceleración es casi el doble que la de la Creality Hi, reduciendo los tiempos de impresión de piezas mecánicas complejas drásticamente.
    * *Puntos Débiles:* Las primeras unidades que salieron al mercado (lotes de 2023) sufrieron de problemas en el extrusor (versión V1) y en el hotend. Creality corrigió esto en las versiones posteriores (extrusor con palanca brillante y boquilla tipo Unicorn), por lo que si adquieres una hoy, te aseguras de tener la versión corregida y madura.
  * **¿Se recomienda usarla a futuro?** Sí, pero bajo ciertas condiciones. Sigue siendo una máquina excepcionalmente rápida y robusta para piezas de ingeniería. Sin embargo, debes tener en cuenta que la K1 original no es compatible con sistemas de impresión multicolor multihilo modernos de manera nativa.

#### **Comparativa PETG vs PLA:**

<div align="center">

|  | PETG | PLA |
|---|---|---|
| **Durabilidad y Resistencia** | Alta durabilidad y tenacidad superior: Al estar modificado con glicol, el PETG impide la cristalización del polímero, resultando en un material altamente tenaz. Bajo esfuerzos mecánicos por impacto, sus cadenas moleculares tienen la flexibilidad necesaria para deformarse elásticamente y absorber la energía cinética del choque. Esto evita la propagación de grietas, haciéndolo ideal para piezas expuestas a colisiones continuas. | Baja durabilidad ante cargas dinámicas: El PLA posee una estructura molecular rígida y cristalina que le otorga una alta dureza superficial, pero carece de la capacidad de disipar energía de forma elástica. Ante colisiones directas o impactos bruscos contra los bordes de la pista, el material estresa sus uniones de capa interlace y tiende a la fractura frágil, quebrándose de manera repentina y catastrófica en lugar de flexionarse. |
| **Resistencia y Estabilidad Térmica** | Excelente inmunidad térmica: Mantiene su integridad estructural y rigidez mecánica en entornos de trabajo de hasta 75°C a 80°C sin experimentar ablandamiento ni distorsión geométrica. Esta propiedad permite montarlo con total seguridad como soporte directo del tren motriz o de placas electrónicas, resistiendo el calor generado por la fricción mecánica y los picos de corriente sin ceder. | Vulnerable al estrés térmico: Su temperatura de transición vítrea (punto de ablandamiento) es críticamente baja, situándose entre los 50°C y 55°C. Si se utiliza en componentes en contacto directo con motores DC bajo carga pesada o reguladores de voltaje que disipan calor por conducción, el PLA pierde su rigidez rápidamente, sufriendo deformaciones geométricas permanentes que descalibran el chasis. |
| **Rigidez Estructural y Flexión** | Módulo elástico moderado (Flexibilidad elástica): Posee una naturaleza semirrígida que le permite soportar vibraciones mecánicas, torsiones y cargas dinámicas continuas sin sufrir fatiga de material. Si bien cede ligeramente ante fuerzas extremas antes de romperse, esta flexibilidad estructural absorbe las oscilaciones del terreno, protegiendo los componentes internos. | Módulo elástico muy elevado (Rigidez absoluta): Presenta una resistencia a la flexión superior, lo que significa que no se dobla ni se deforma bajo cargas estáticas moderadas. Esta ausencia de flexibilidad elástica es una ventaja técnica para piezas estáticas del robot que requieren mantener una posición fija e invariable, neutralizando cualquier flexión parasitaria o pandeo. |
| **Resistencia Química y Ambiental** | Alta inercia química e hidrofobicidad: Es químicamente inerte y exhibe una resistencia sobresaliente ante aceites, grasas, lubricantes mecánicos y alcoholes de limpieza. Al ser completamente hidrofóbico, no se debilita por la humedad ambiental tras su impresión y su alta estabilidad frente a la radiación UV garantiza que las piezas mantengan sus propiedades mecánicas intactas. | Sensible a la degradación a largo plazo: Al ser un biopolímero derivado de fuentes orgánicas, es propenso a la degradación acelerada bajo la exposición continua a rayos UV o cambios de humedad drásticos. Además, su resistencia química frente a agentes externos como alcoholes, aceites o lubricantes de hardware es limitada, lo que puede debilitar las paredes de la pieza con el tiempo. |
| **Precisión Dimensional y Encajes** | Tolerancias moderadas y propenso a hilos: Al requerir temperaturas de extrusión más altas, el material experimenta una mayor contracción térmica al enfriarse, lo que exige calibrar el flujo para evitar variaciones dimensionales en encajes milimétricos. Además, su alta viscosidad tiende a generar stringing (hilos finos) que requieren postprocesado en zonas de movimiento mecánico fino. | Tolerancias geométricas perfectas: Debido a su bajísima contracción térmica al enfriarse, el PLA destaca por una estabilidad dimensional milimétrica. Permite imprimir roscas, encajes de rodamientos y uniones mecánicas finas con errores de tolerancia prácticamente nulos, asegurando que las piezas encajen de manera exacta y sin holguras desde el primer prototipo. |

</div>

---

## 4. Componentes 

El enfoque de nuestro prototipo es que el robot sea de bajo coste y sea más pequeño a diferencia del que utilizamos a principio de año, permitiendo comparar precios y eficiencias.

<div align="center">

**Versión Actual**

| Cantidad | Productos | Precio | Total |
|---|---|---|---|
| 1 | [Raspberry Pi Zero 2W](https://www.amazon.com/-/es/Raspberry-Pi-Zero-2W-inal%C3%A1mbrico/dp/B0C9TW4BNK) | $90 | $90 |
| 1 | [URGENEX Lithium-ion Battery](https://www.amazon.com/URGENEX-2000mAh-Battery-Rechargeable-Helicopter/dp/B0CJNNMST2) | $22 | $22 |
| 2 | [Servo MG90S](amazon.com/-/es/Miuzei-Engranaje-Metálico-Helicóptero-Proyecto/dp/B0BWJ41FZB) | $9 | $9 |
| 1 | [Mini Micro N20 Motor](https://www.amazon.com/-/es/Acxico-unids-engranajes-velocidad-completo/dp/B09DG3GCGK) | $10 | $10 |
| 4 | [DRV8833 Dual Motor Driver](http://pololu.com/product/2130) | $11 | $11|
| 1 | [Arducam 8MP IMX219 Camera Module](https://www.amazon.com/-/es/Arducam-M%C3%B3dulo-Raspberry-distorsi%C3%B3n-compatible/dp/B09VSRH14M?th=1) | $20 | $20 |
| 1 | [Mini360 Mini 360 3A DC-DC](https://www.amazon.com/-/es/Mini360-Aumento-Convertidor-Potencia-Boost-Down/dp/B0D3QSYRFT) | $15 | $15 |
| 1 | [VL53L0X Time of Flight](https://www.amazon.com/VL53L0X-Breakout-GY-VL53L0XV2-medici%C3%B3n-distancia/dp/B0DP6893DS) | $15 | $15 |
| 1 | [Gikfun in Touch Switch](https://www.amazon.com/-/es/Gikfun-Interruptor-0-472x0-472x0-287-moment%C3%A1neo-colores/dp/B01E38OS7K/) | $10| $10 |
| | | | **$202** |

**Antigua previa**

| Cantidad | Productos | Precio | Total |
|---|---|---|---|
| 1 | [Raspberry Pi 4 B](https://www.amazon.com/Raspberry-Model-2019-Quad-Bluetooth/dp/B07TC2BK1X) | $123.99 | $123.99 |
| 1 | [Yfrobot steering chassis](https://yfrobot.com/products/steering-gear-robot) | $118.50 | $118.50 |
| 2 | [Zeee 3S Lipo Battery 2200mAh 11.1V 50C](https://www.amazon.nl/Zeee-Vrachtwagen-Vliegtuig-Quadcopter-Helikopter/dp/B0C2CHMCC3) | $50.65 | $50.65 |
| 1 | [Arducam 8MP IMX219 175°](https://www.amazon.com/Arducam-IMX219-Degree-Raspberry-Compatible/dp/B09VSVB4DT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) | $26.99 | $26.99 |
| 4 | [Lever wire connectors](https://www.amazon.com/Conductor-Compact-Connectors-Electrical-Terminals/dp/B0D9Y5XFQC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) | $9.99 | $9.99|
| 1 | [Buck Converter 3A 15W Type-C](https://www.amazon.com/-/es/Convertidor-Impermeable-Adaptador-corriente-compatible/dp/B0D2MTJQK8) | $8.79 | $8.79 |
| 1 | [MAKEBLOCK MegaPi (from mbot mega)](https://www.robotshop.com/products/makeblock-mbot-mega-robot-car-rechargeable-li-po-battery-kit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) | $148.97 | $148.97 |
| 1 | [Crash Collision Sensor Module](https://www.amazon.com/-/es/Generic-detecci%C3%B3n-colisi%C3%B3n-interruptor-Arduino/dp/B0D6GZDV95) | $5.54 | $5.54 |
| 1 | [LED Traffic Light Module](https://www.amazon.com/Traffic-Light-Module-Board-Arduino/dp/B07R1KJ4DT) | $10.99| $10.99 |
| | | | **$504.41** |

</div>

<div align="center">

| Foto | Descripción |
|---|---|
| **Raspberry Pi Zero 2W** <div  align="center"> <div  style="width:290 px"> <img width="466" height="227" alt="51nIyTxfaQL _AC_SX466" src="https://github.com/user-attachments/assets/68e57edf-f712-4b01-b716-4459a832151a" /> </div> </div>  | Se ha seleccionado la Raspberry Pi Zero 2W como el cerebro de procesamiento de alto nivel debido a su factor de forma ultra compacto y ligero permite integrarla fácilmente en chasis con restricciones espaciales estrictas (como vehículos autónomos a escala) sin comprometer la capacidad de ejecutar tareas complejas de visión por computadora con OpenCV (procesamiento de imágenes, detección de contornos o calibración por espacios de color en tiempo real) y comunicación serial fluida con microcontroladores secundarios, manteniendo además una excelente relación calidad-precio y un consumo energético eficiente para sistemas móviles alimentados por batería. |
| **URGENEX Lithium-ion Battery** <div align="center"> <img width="466" height="511" alt="71hyN7C7cyL _AC_SX466" src="https://github.com/user-attachments/assets/87c113c3-e2ff-4e0e-89fa-203eb6924d54" /> </div> | Se ha seleccionado la batería URGENEX como la fuente de alimentación principal del sistema debido a su excelente relación entre densidad energética, peso ligero y factor de forma compacto, lo que permite alojarla sin inconvenientes en compartimentos de chasis reducidos. Su capacidad de entrega de corriente constante garantiza una alimentación estable y libre de caídas de tensión repentinas para los sistemas de procesamiento de alto nivel (como la Raspberry Pi) y los controladores de motores, previniendo reinicios inesperados del sistema durante picos de aceleración o exigencia mecánica. Además, su alta tasa de descarga y su prolongada vida útil por ciclos de carga aseguran una autonomía óptima durante las pruebas de rendimiento y validación del robot. |
| **Servo MG90S** <div  align="center"> <img width="1200" height="1200" alt="micro-servo-mg90s" src="https://github.com/user-attachments/assets/9565c879-ab06-4f3c-b8ea-24e16dcc4b83" /> </div> | Se ha seleccionado el servomotor MG90S debido a su robusta construcción con engranajes metálicos y un diseño compacto de peso ligero (aproximadamente 13.4 gramos), lo que garantiza una excelente resistencia ante los impactos, el desgaste mecánico y las vibraciones constantes generadas durante el desplazamiento del vehículo. Su capacidad para ofrecer un control preciso de posición angular mediante modulación por ancho de pulso (PWM) lo convierte en el actuador ideal para tareas que exigen alta confiabilidad, tales como mecanismos de dirección o la orientación dinámica de sensores, manteniendo un rendimiento superior y una mayor vida útil en comparación con los servos de engranajes plásticos convencionales. |
| **Mini Micro N20 Motor** <div  align="center"> <img width="447" height="447" alt="images" src="https://github.com/user-attachments/assets/d2060b21-e2a8-4057-ba9a-749c32249cd6" /> </div> | Se ha seleccionado el motor DC con reductora N20 debido a su excepcional densidad de potencia y su factor de forma ultra compacto, lo que permite maximizar el espacio interior del chasis sin sacrificar la capacidad de tracción. Gracias a su caja reductora metálica integrada, este motor ofrece un torque de salida elevado a bajas revoluciones por minuto (RPM), garantizando un desplazamiento controlado, preciso y con la fuerza necesaria para superar fricciones y pendientes ligeras, manteniendo al mismo tiempo un consumo de corriente eficiente para sistemas alimentados por batería. |
| **DRV8833 Dual Motor Driver** <div  align="center"> <img width="600" height="480" alt="0J3864 600x480" src="https://github.com/user-attachments/assets/85700e08-3852-4edd-b3cb-3e5abd94c6ae"/> </div> | Se ha seleccionado el driver DRV8833 debido a su excelente rendimiento en el control independiente de dos motores de corriente continua (DC) a través de señales PWM, ofreciendo un factor de forma sumamente compacto ideal para chasis con restricciones de espacio. Este componente destaca por su capacidad de entregar una corriente continua adecuada para micromotores (como los N20), integrando además protecciones fundamentales como limitación de corriente, protección térmica y apagado por subtensión, lo que garantiza una alta confiabilidad y previene daños en la electrónica ante bloqueos mecánicos imprevistos en las ruedas. |
| **Arducam 8MP IMX219 Camera Module** <div  align="center"> <img width="466" height="466" alt="61jMkIIKgRL _AC_SX466" src="https://github.com/user-attachments/assets/db3b2f6e-8b46-4063-8d08-f1acd0ed3ad0"/> </div> | Se ha seleccionado el módulo de cámara Arducam de 8 megapíxeles (basado en el sensor Sony IMX219) debido a su excelente calidad de imagen, nitidez y capacidad para capturar fotogramas en alta resolución con una baja distorsión. Su interfaz de conexión directa tipo CSI permite una comunicación de bajo nivel rápida y sin latencia perceptible con el ordenador de placa reducida, optimizando la tasa de cuadros por segundo (FPS). Esto resulta fundamental para la ejecución fluida de algoritmos avanzados de visión por computadora mediante bibliotecas como OpenCV y MediaPipe, garantizando un rendimiento preciso en tareas de navegación autónoma, seguimiento de líneas o detección de objetos. |
| **Mini360 Mini 360 3A DC-DC** <div  align="center"> <img width="497" height="500" alt="D_NQ_NP_618070-MLV84321896073_052025-O" src="https://github.com/user-attachments/assets/d9e8c019-d68f-4306-a678-4b3ace395889" /> </div> | Se ha seleccionado el módulo regulador Mini360 debido a su alta eficiencia en la conversión de energía de tipo reductor (step-down), lo que permite transformar la tensión de la batería principal (por ejemplo, 7.4V) a un voltaje lógico estable y seguro (como 5V) para los ordenadores de placa reducida y microcontroladores. A diferencia de los reguladores lineales tradicionales, este convertidor de conmutación minimiza drásticamente la disipación de calor por efecto Joule y aprovecha al máximo la energía disponible. Su factor de forma ultra compacto facilita su integración directa en espacios reducidos dentro de la circuitería del chasis, garantizando una alimentación limpia y continua libre de caídas de tensión imprevistas. |
| **VL53L0X Time of Flight** <div  align="center"> <img width="554" height="554" alt="images" src="https://github.com/user-attachments/assets/d9a842a8-ccb8-4556-8bb5-d3f23b5e3a5b" /> </div> | Se han seleccionado los sensores láser VL53L0X basados en la tecnología Time-of-Flight (ToF) y situados en los laterales del vehículo debido a su capacidad para medir distancias absolutas con alta precisión milimétrica, independientemente de la reflectancia o el color de la superficie del objeto detectado. A diferencia de los sensores infrarrojos tradicionales basados en intensidad de luz, el VL53L0X calcula el tiempo exacto que tarda un pulso de luz láser invisible (VCSEL de clase 1) en rebotar en el entorno, lo que garantiza lecturas extremadamente fiables y estables frente a variaciones de iluminación ambiental. Su disposición lateral resulta fundamental para ejecutar algoritmos de control de posición, mantener el centrado del vehículo en pasillos o pistas, y detectar paredes u obstáculos perimetrales de forma anticipada. |
| **Gikfun in Touch Switch** <div  align="center"> <img width="1600" height="1600" alt="AE1027-10_2048x" src="https://github.com/user-attachments/assets/fc90092c-fffa-402e-8f2e-7ecc8abb5326" /> </div> | Se ha seleccionado un interruptor táctil de la marca Gikfun para gestionar el encendido general del vehículo con el fin de proporcionar un mecanismo de activación fiable, ergonómico y de bajo perfil. Este componente permite realizar el corte o suministro de energía principal de manera limpia y sin la necesidad de interruptores mecánicos voluminosos o expuestos que puedan sufrir desgaste físico prematuro o falsos contactos debido a las vibraciones del terreno. Su integración facilita un acceso rápido y seguro al sistema eléctrico durante las pruebas operativas y las fases de validación del robot. |

</div>

### 4.1. Disposicion y justificacion 

El diseño de nuestro vehículo autónomo se fundamenta en una arquitectura modular de tres niveles verticales, optimizada para la gestión eficiente del centro de gravedad, el balance de masas y la mitigación de interferencias electromagnéticas y mecánicas. Esta configuración jerárquica por "pisos" permite aislar los elementos mecánicos de potencia frente a los módulos lógicos de procesamiento y visión artificial.

#### Arquitectura del Chasis por Niveles:

* **1er nivel (Planta Baja):**
  Constituye la base estructural y el tren de rodaje del vehículo. En este nivel se ubica el Traction System (tracción trasera 2WD con transmisión de engranajes internos impulsada por el micromotor N20), el Steering System asistido por el servomotor metálico MG90S en el eje delantero, y el arreglo de sensores láser de tiempo de vuelo VL53L0X.
  * *Justificación Técnica:* Colocar los actuadores mecánicos y el sistema de tracción en la planta baja garantiza un centro de gravedad pegado al suelo. Al utilizar un sistema 2WD trasero, se asegura una transferencia de peso óptima hacia el eje motriz durante las aceleraciones, mientras que el servo MG90S proporciona robustez direccional directa.

* **2do nivel (Planta Intermedia):**
  Situado sobre el tren de tracción, este nivel alberga el suministro energético y la etapa de control de hardware. Aquí se encuentra encapsulada la Batería LiPo URGENEX de 7.4V. Justo por encima de ella, se ubica la Custom PCB que consolida el driver DRV8833 y el Buck Converter Mini360. En la parte posterior de este nivel se integra el interruptor principal (SW Gikfun).
  * *Justificación Técnica:* Centralizar la batería LiPo en el piso medio alinea la mayor masa del vehículo con el centro geométrico, reduciendo los momentos de inercia polares para evitar subvirajes o sobrevirajes. La Custom PCB actúa como puente intermedio de distribución: agrupa la reducción de voltaje (Mini360) y la etapa de potencia (DRV8833) manteniendo rutas de cableado muy cortas hacia los motores del primer nivel y protegiendo de ruido electromagnético al nivel superior. El interruptor trasero permite cortes de energía rápidos y accesibles.

* **3er nivel (Planta Superior):**
  Corresponde a la cúspide de la estructura, dedicada de forma exclusiva al procesamiento lógico y la percepción geométrica. Contiene la computadora a bordo Raspberry Pi Zero 2W y el conjunto elevado de la cámara Arducam IMX219 (Cam).
  * *Justificación Técnica:* Elevar la Pi Zero 2W la aísla por completo de las vibraciones mecánicas de la reductora del N20 y de los bucles de corriente del chasis inferior. El factor de forma ultracompacto de la Pi Zero reduce drásticamente el peso en la parte superior del péndulo invertido del chasis, manteniendo la agilidad del vehículo sin sacrificar la capacidad de procesamiento con OpenCV.

#### Sistema de Percepción y Orientación Espacial:

Esta distribución tridimensional complementa la estrategia de navegación autónoma, asegurando zonas de cobertura óptimas:

* **Distribución de Visión Artificial (3er nivel):**
  La cámara Arducam de 8MP se posiciona en un brazo articulado impreso en 3D que se proyecta hacia adelante y arriba, con un ángulo de inclinación fijo hacia la pista. Esta elevación es crítica para expandir el campo de visión del sensor, permitiendo al algoritmo abarcar una Región de Interés (ROI) amplia para identificar límites de pista y códigos de color de forma anticipada sin que la propia trompa del carro obstruya el encuadre.

* **Distribución de sensor Frontal (1er nivel):**
  Se utiliza un sensor ToF VL53L0X montado directamente sobre la base del chasis en una posición baja y avanzada. Esta sincronización geométrica permite que el láser actúe como un bypass de seguridad de hardware en tiempo real: mientras la cámara toma decisiones lógicas a nivel macro, el VL53L0X inferior detecta los paredes para los dos primeros retos de forma absoluta y sin depender de la iluminación para ejecutar rutinas de evasión o frenado.

* **Distribución de sensores Laterales (1er nivel):**
  Los sensores ToF de flanco están posicionados simétricamente en el primer nivel, leyendo distancias milimétricas hacia las paredes de la pista. Ubicarlos cerca del suelo y simétricos respecto al centro de masa minimiza las lecturas erróneas causadas por el cabeceo del chasis en aceleraciones o frenadas. Al utilizar tecnología de tiempo de vuelo en lugar de ultrasonidos, se garantiza que los algoritmos de estabilización y centrado reciban datos inmunes al ruido acústico de los motores y a los reflejos de las paredes.

<div align="center">

<img width="4080" height="3060" alt="20260829_205432" src="https://github.com/user-attachments/assets/14a58644-2533-4508-8e80-18146f99838e" />

NOTA: En esta imagen los sensores de tiempo de vuelo no estan acoplados. 

</div>

---

## 5. Presupuesto de energia 

Para garantizar la eficiencia y compacidad del vehículo, hemos implementado una arquitectura de alimentación centralizada utilizando una única batería URGENEX 2S LiPo de 7.4V y 2200mAh (50C). Esta configuración alimenta todos los subsistemas, empleando un módulo de regulación para proteger los componentes lógicos:

* **Circuito de Potencia:** Alimentado desde la línea principal de la batería tras pasar por el interruptor, este bus suministra el voltaje directo a los actuadores de mayor consumo: el driver de motor DRV8833 (que controla el motor N20 de la transmisión 2WD) y el servomotor de dirección MG90S.

* **Circuito de Lógica y Visión:** Derivado de la línea principal, el voltaje pasa por un módulo Buck Converter Mini 360, el cual reduce y estabiliza el voltaje a 5.0V para alimentar de forma segura la Raspberry Pi Zero 2W. Esta separación protege a la computadora a bordo de las caídas de tensión (transitorios) provocadas por los arranques repentinos del motor de tracción, evitando que la interferencia electromagnética (EMI) induzca ruido en la señal de video o provoque reinicios del sistema.

Esta configuración nos permite operar con la máxima seguridad, garantizando que, incluso bajo condiciones de estrés mecánico severo en la dirección y tracción, nuestro "cerebro" (Raspberry Pi) mantenga una alimentación constante y limpia para procesar la trayectoria con total precisión.

<div align="center">

| Componentes | Cantidad | Voltaje de Operación | Consumo Nominal/Pico | Consumo Total |
|---|---|---|---|---|
| **Raspberry Pi Zero 2W** | 1 | 5.0 V | 100 mA / 350 mA | 350 mA |
| **Servo MG90S** | 1 | 4.8 V / 6.0 V | 200 mA / 700 mA | 700 mA |
| **Mini Micro N20 Motor** | 1 | 3 V / 12 V | 60 mA / 750 mA | 750 mA |
| **DRV8833 Dual Motor Driver** | 1 | 2.7 V / 10.8 V | 750 mA | 750 mA |
| **Arducam 8MP IMX219 Camera Module** | 1 | 3.3 V | 200 mA / 300 mA | 300 mA |
| **Mini360 Mini 360 3A DC-DC** | 1 | 4.75 V / 23 V | 15 mA (reposo) / 3000 mA (Límite) | 15 mA |
| **VL53L0X Time of Flight** | 2 |  2.6 V / 5.5 V | 10 mA / 20 mA (c/u) | 20 mA |
| **Gikfun in Touch Switch** | 1 |  2.0 V / 5.5 V | 4 mA / 8 mA | 8 mA |
| **Total** | | |  589 mA / 2173 mA (2.17 A) | 2173 mA (2.17 A) |

</div>

#### Conclusión del Presupuesto:

El consumo total del sistema alcanza los 2.17 A en condiciones de carga máxima (stall). La utilización de una única batería LiPo con una alta tasa de descarga (50C) está dimensionada holgadamente para soportar los picos de corriente del motor N20 y el servo MG90S de forma simultánea. El Buck Converter Mini 360 actúa como barrera protectora, asegurando que, aunque los actuadores alcancen su máximo esfuerzo mecánico en la pista, la Raspberry Pi Zero 2W mantenga un voltaje estable de 5.0V, garantizando el procesamiento ininterrumpido del algoritmo de visión.

### 5.1. Diagrama de cableado 

La arquitectura eléctrica de nuestro carro se basa en un diseño simplificado y directo para minimizar puntos de falla mecánicos. El cableado se divide de la siguiente manera:

#### Distribución de Energía Principal:
* **Batería y Encendido:** La energía proviene de la batería URGENEX LiPo de 7.4V, pasando por un interruptor principal que energiza todo el circuito simultáneamente.
* **Dominio de Potencia (Bus de Fuerza):** Desde el interruptor, el voltaje directo (7.4V) se bifurca mediante cableado de mayor calibre hacia el driver DRV8833 (para el control del motor de tracción N20) y hacia el servomotor de dirección MG90S.
* **Regulación de Voltaje:** En paralelo, la energía llega al Buck Converter Mini 360. Este módulo step-down se encarga de reducir de forma eficiente el voltaje de la batería y estabilizarlo a 5.0V constantes, actuando como filtro contra el ruido eléctrico generado por la tracción.

#### Dominio de Lógica y Control:
* **Computadora a Bordo:** La Raspberry Pi Zero 2W recibe los 5.0V regulados desde el Buck Converter a través de sus pines GPIO. Desde la Pi se envían las señales lógicas de control (PWM/Digitales) hacia el driver DRV8833 y el servo MG90S.
* **Percepción Visual:** La cámara Arducam se conecta directamente al puerto CSI de la Pi Zero 2W, asegurando un flujo de datos de baja latencia.
* **Sensores de Distancia:** Los tres sensores de tiempo de vuelo VL53L0X se comunican a través del bus I2C de la Raspberry Pi. Comparten las mismas líneas de reloj (SCL), datos (SDA), alimentación y tierra (GND), manteniendo rutas cortas para evitar la captación de interferencia electromagnética (EMI).

<div align="center">

<img width="1518" height="688" alt="Diagrama de cableado" src="https://github.com/user-attachments/assets/64c91c6a-99f8-4729-aea7-bc2c2aa19d2f" />

</div>

---

## 6. Software 

### 6.1. Herramientas de apoyo 

* **Color Detector:** Es una herramienta interactiva de calibración visual diseñada para segmentar y aislar colores específicos en tiempo real mediante el espacio de color LAB (Luminancia, A y B) y filtros de desenfoque gaussiano. El sistema captura el flujo de video de una Picamera2, aplica transformaciones morfológicas de erosión y dilatación para limpiar el ruido de la imagen, y genera una máscara binaria basada en umbrales máximos y mínimos ajustables por deslizadores en una interfaz gráfica (GUI) construida con CustomTkinter. Su función principal es preajustar firmas de color (como rojo, verde, azul o negro) y exportar estos rangos óptimos a un archivo de configuración JSON para que el robot pueda reconocer objetos o líneas de manera estable bajo diferentes condiciones de luz.

  <div align="center">

  <img width="4080" height="3060" alt="1000267395" src="https://github.com/user-attachments/assets/61a42bbf-493c-4b45-b054-bdce386a2613" />

  </div>

* **ROI Detector:** Es una utilidad de configuración espacial basada en OpenCV que permite delimitar "Regiones de Interés" (ROI) personalizadas sobre la transmisión de video de la cámara mediante clics y arrastres del mouse. El script escala el fotograma original de forma proporcional dentro de un lienzo centrado con bordes negros constantes, permitiendo al usuario dibujar múltiples cuadrantes, visualizando dinámicamente sus dimensiones en píxeles. Su propósito principal es limpiar la memoria caché con la tecla 'C' o finalizar la captura con la tecla 'ESC' para activar una ventana flotante de Tkinter que exporta de forma automatizada las coordenadas $(x_1, y_1, x_2, y_2)$ estructuradas como una lista de objetos en un archivo nativo de Python (.py), aislando las zonas específicas de análisis visual donde el robot debe procesar la información (como la línea del suelo) e ignorando el ruido del entorno.

  <div align="center">

  <img width="4080" height="3060" alt="1000266075" src="https://github.com/user-attachments/assets/861c2725-2a80-4ced-9f3a-0248037ec576" />

  </div>

### 6.2. Instalación en *shell* 

```
#!/bin/bash

# ==========================================
# SCRIPT DE INSTALACIÓN: OpenCV (C++) + GStreamer + GPIO
# Optimizado para Raspberry Pi Zero (Bookworm/Bullseye)
# SIN soporte de Python
# ==========================================

set -e # Detener el script si ocurre un error

echo "=================================================="
echo " 🚀 Iniciando instalación del entorno de Visión y GPIO (C++)"
echo "=================================================="

# 1. Actualizar el sistema
echo "[1/5] Actualizando lista de paquetes del sistema..."
sudo apt update -y
sudo apt upgrade -y

# 2. Instalar dependencias de GStreamer y Cámara (libcamera)
echo "[2/5] Instalando GStreamer y plugins de cámara (libcamerasrc)..."
sudo apt install -y \
    gstreamer1.0-tools \
    gstreamer1.0-plugins-base \
    gstreamer1.0-plugins-good \
    gstreamer1.0-plugins-bad \
    gstreamer1.0-plugins-ugly \
    gstreamer1.0-libcamera \
    libgstreamer1.0-dev \
    libgstreamer-plugins-base1.0-dev

# 3. Instalar OpenCV SOLO para C++ (sin python3-opencv)
echo "[3/5] Instalando OpenCV para C++ (con soporte GStreamer)..."
sudo apt install -y \
    libopencv-dev \
    opencv-data \
    pkg-config

# 4. Instalar librerías para controlar GPIO desde C++
echo "[4/5] Instalando librerías para control de GPIO..."
# Opción A: libgpiod (El estándar moderno y recomendado en Bookworm)
sudo apt install -y libgpiod-dev gpiod
# Opción B: pigpio (Más antiguo, pero muy fácil de usar)
sudo apt install -y pigpio libpigpio-dev

# 5. Configurar permisos de usuario
echo "[5/5] Configurando permisos de usuario para video y gpio..."
sudo usermod -aG video,gpio,dialout $USER

# Corrección del warning de Zenity
echo "Corrigiendo permisos del directorio de runtime (para Zenity)..."
sudo chmod 700 /run/user/$(id -u) 2>/dev/null || true

echo "=================================================="
echo " ✅ ¡INSTALACIÓN COMPLETADA CON ÉXITO!"
echo "=================================================="
echo "⚠️ IMPORTANTE: Debes REINICIAR tu Raspberry Pi para que"
echo "   los nuevos permisos de grupo (video, gpio) surtan efecto."
echo "   Ejecuta: sudo reboot"
echo "=================================================="
```

### 6.3. Compilación y ejecución de archivos (codigos del carro) 

**DATO IMPORTANTE:** Primero que todo hay que acceder a la carpeta donde están los códigos del carro para iniciarlos. En nuestro caso está escrito así:

```
cd code/LNM/src/visioncontroller
```

##### Reto 1
- *Compilación de app.cpp*
```
g++ -O2 app.cpp vision_controller.cpp -o vision_app `pkg-config --cflags --libs opencv4` -lpigpio -pthread -lrt
```

- *Ejecución de app.cpp*
```
sudo -E ./vision_app
```

##### Reto 2
- *Compilación de app2.cpp*
```
g++ -O2 app2.cpp vision_controller.cpp -o vision_app2 `pkg-config --cflags --libs opencv4` -lpigpio -pthread -lrt
```

- *Ejecución de app2.cpp*
```
sudo -E ./vision_app2
```

*Dato extra:* Usamos el **bash** para abreviar las lineas de código para compilar y ejecutar juntos y cuando se quiere ejecutar, solo usaremos la linea de ejecución.

### 6.4. Abreviaciones con Bash 

##### Reto 1
Creamos un bash escribiendo:

```
nano ./app.sh
```

Ahora hay que escribir:
```
g++ -O2 app.cpp vision_controller.cpp -o vision_app `pkg-config --cflags --libs opencv4` -lpigpio -pthread -lrt
sudo -E ./vision_app
```

Le damos a las teclas *Ctrl+O* y al final *Enter*.

**Al final solo se necesita ejecutar en la terminal ./app2.sh**

##### Reto 2
Creamos un bash escribiendo:

```
nano ./app2.sh
```

Ahora hay que escribir:
```
g++ -O2 app2.cpp vision_controller.cpp -o vision_app2 `pkg-config --cflags --libs opencv4` -lpigpio -pthread -lrt
sudo -E ./vision_app2
```

Le damos a las teclas *Ctrl+O* y al final *Enter*.

**Al final solo se necesita ejecutar en la terminal ./app2.sh**

### 6.5. Megapi controller(Deprecated) 

Esta es una descripción completa de todos los atributos y métodos de la clase `MegaPiController`, junto con sus argumentos. Te recomendamos que la consultes primero antes de pasar a las demás secciones y que, cuando clones el repositorio, la utilices como guía para orientarte en nuestro código.

**mega_pi_controller.py (clase MegaPiController)**

**Dependencias:**
* `serial`
* `time`
* `threading`
* `pandas`
* `random`
* `json`
* `cv2`
* `src.vision_controller.VisionController`
* `dataclasses.dataclass`

**Descripción del método constructor:**

```python
def __init__(self, port='COM9', baudrate=115200):
    """
    Inicializa la conexión serial con la placa MegaPi y registra los subsistemas.
    Si la conexión falla, termina el proceso con un mensaje de error crítico.
    """
```

El constructor establece un canal de comunicación a través de puerto serial por hardware con el microcontrolador MegaPi. Inicia automáticamente un hilo de escucha en segundo plano (`_read_telemetry`) para capturar las métricas de hardware entrantes de forma asíncrona, inicializa el subsistema de visión artificial (`VisionController`), carga las máscaras de color predefinidas desde estructuras JSON específicas y prepara los registros internos, las variables de estado y las Regiones de Interés (ROIs) para el seguimiento espacial y de líneas.

<div align="center">

**Descripción de atributos:**

| Atributo | Tipo de dato | Funcionalidad |
| --- | --- | --- |
| `ser` | `serial.Serial` | Representa el canal de comunicación serial por hardware de bajo nivel con la MegaPi. |
| `dist_front` | `int` | Almacena el valor de distancia en tiempo real (cm) capturado por el sensor ultrasónico central. |
| `dist_left` | `int` | Almacena el valor de distancia en tiempo real (cm) capturado por el sensor ultrasónico izquierdo. |
| `dist_right` | `int` | Almacena el valor de distancia en tiempo real (cm) capturado por el sensor ultrasónico derecho. |
| `ir_left` | `int` | Almacena el valor porcentual bruto de reflectancia ($0\%$ a $100\%$) del sensor IR izquierdo TCRT5000. |
| `ir_right` | `int` | Almacena el valor porcentual bruto de reflectancia ($0\%$ a $100\%$) del sensor IR derecho TCRT5000. |
| `data_log` | `list[dict]` | Registro volátil en memoria utilizado para encolar los pasos de telemetría destinados al guardado de datos de entrenamiento. |
| `log_index` | `int` | Contador de pasos continuo auto-incrementable para el dataframe del registro de telemetría. |
| `vision` | `VisionController` | Módulo central instanciado responsable de las capturas de fotogramas y del mapeo de contornos LAB/HSV. |
| `running` | `bool` | Variable booleana de control de ejecución de alto nivel utilizada para terminar de forma segura las operaciones del hilo en segundo plano. |
| `reader_thread` | `threading.Thread` | Hilo de trabajo daemon asíncrono dedicado a sondear los paquetes de carga útil serial entrantes. |
| `button_value` | `int` | Representación binaria del estado del botón físico integrado en la placa para el inicio del sistema. |
| `turning_direction` | `int` | Rastrea la configuración del diseño del carril ($0$: No asignado, $1$: Sentido horario/Azul, $2$: Sentido antihorario/Naranja). |
| `rois` | `list[ROI]` | Define cuadros de procesamiento fijos en código para el análisis del área de la pared frontal y las líneas de la pista. |

</div>

**Descripción de métodos:**

<div align="center">

| Método | Argumentos | Retorno | Descripción |
| --- | --- | --- | --- |
| `_read_telemetry()` | Ninguno | `None` | Hilo de trabajo de sondeo continuo. Decodifica un formato de carga útil rígido de 8 bytes prefijado por un byte de cabecera `0xAA`. |
| `_send_command()` | `action: int`, `v1: int`, `v2: int` | `None` | Empaqueta y transmite instrucciones de protocolo de control de bajo nivel de 5 bytes prefijadas con una bandera de comando `0xFF`. |
| `get_masks()` | `color: str` | `list` | Abre los archivos de configuración local de matrices de color y extrae los arreglos de límites numéricos. |
| `load_masks()` | Ninguno | `None` | Método de arranque secuencial que mapea los límites de los colores rojo, verde, azul, naranja y negro dentro del objeto. |
| `obtenerarea_frontal()` | Ninguno | `None` | Consulta los volúmenes de masa de contornos negros a lo largo de la ROI del horizonte frontal superior. |
| `obtener_linea_azul()` | Ninguno | `None` | Segmenta y evalúa el perfil del diseño de la línea de seguimiento buscando activadores de la pista azul. |
| `obtener_linea_naranja()` | Ninguno | `None` | Segmenta y evalúa el perfil del diseño de la línea de seguimiento buscando activadores de la pista naranja. |
| `debug_UI()` | Ninguno | `None` | Motor de superposición gráfica que muestra los bucles de seguimiento dinámico de visión artificial en una ventana de fotograma local. |
| `log_step()` | `action_code: int` | `None` | Añade los valores de las variables en tiempo real (ultrasónicos, infrarrojos) al arreglo del registro local. |
| `move_forward()` | `speed: int`, `log: bool` | `None` | Invoca los actuadores de tracción de bajo nivel para fijar la marcha hacia adelante a las velocidades seleccionadas. |
| `move_backward()` | `angle: int`, `speed: int`, `log: bool` | `None` | Activa vectores de movimiento en reversa mientras fija los eslabones de dirección a un ángulo de escape. |
| `turn_direction()` | Ninguno | `None` | Macro de control reactivo que enruta los pasos de giro basándose en los estados actuales de dirección. |
| `turn_left()` | `angle: int`, `speed: int`, `log: bool` | `None` | Ajusta los eslabones del servo mecánico Ackermann a ángulos cerrados hacia la izquierda bajo velocidades de tracción fijas. |
| `turn_right()` | `angle: int`, `speed: int`, `log: bool` | `None` | Ajusta los eslabones del servo mecánico Ackermann a ángulos cerrados hacia la derecha bajo velocidades de tracción fijas. |
| `turn_center()` | `log: bool` | `None` | Recalibra los pulsos del servo de dirección activa de vuelta a las coordenadas del centro geométrico. |
| `stop()` | `log: bool` | `None` | Desactiva los registros de velocidad activos de inmediato para cortar la energía de los motores y detener el vehículo. |
| `get_distances()` | Ninguno | `tuple[int, int, int]` | Getter estándar de telemetría que devuelve una tupla compuesta por las métricas actuales de los sensores (frontal, izquierdo, derecho). |
| `get_ir_reflectance()` | Ninguno | `tuple[int, int]` | Devuelve una tupla en tiempo real que contiene los porcentajes de reflectividad infrarroja localizada ($0-100\%$). |
| `save_data_to_csv()` | `filename: str` | `None` | Compila los volcados de datos encolados directamente en estructuras mapeadas por índices en el disco a través de Pandas. |
| `close()` | Ninguno | `None` | Libera los manejadores de procesos, envía un comando de parada total y cierra de forma segura los puertos seriales abiertos. |
| `start()` | Ninguno | `bool` | Evalúa los estados del botón. Devuelve `True` si el botón está liberado (HIGH/0), manteniendo el bucle en ejecución. |

</div>

## 6.6. Challenge Overview 

### **WRO 2026 Future Engineers Challenges:** 

Dos retos distintos de navegación autónoma que ponen a prueba la inteligencia y la precisión de los vehículos.

</div>

### 6.6.1. **Open Challenge** 

<div align="center">

**Objetivo:** Completar tres vueltas autónomas en pistas configuradas dinámicamente.

| Aspectos | Retos | Nuestra solución |
|---|---|---|
| **Variabilidad de la pista** | Ubicación aleatoria de las paredes internas | Algoritmos adaptativos de planificación de ruta |
| **Navegación** | Trazados desconocidos de la pista en cada ronda | Seguimiento robusto de las paredes con detección de esquinas |
| **Rendimiento** | Tiempos de vuelta consistentes a pesar de las variaciones | Control PID optimizado y fusión de cámaras |
| **Precisión** | Mantener el rumbo en carriles estrechos | Dirección y control de velocidad de alta precisión |

</div>

### 6.6.2. **Obstacle Challenge** 

<div align="center">

**Objetivo:** Recorrer tres vueltas respetando las señales de tránsito y estacionando con precisión.

| Elemento del desafío | Requisito | Nuestra implementación |
|---|---|---|
| **Señales de tránsito** | Rojo → Desviación hacia la derecha<br>Verde → Desviación hacia la izquierda | Detección de color en tiempo real con el espacio de color LAB |
| **Equive de obstáculos** | Ajuste dinámico de la trayectoria | Seguimiento fluido a distancias constantes |
| **Maniobra de estacionamiento** | Estacionamiento en paralelo tras completar una vuelta | Estacionamiento en varias etapas con validación por camara |
| **Navegación** | Optimización de la ruta más corta | Ruteo eficiente alrededor de combinaciones de obstáculos |

</div>

---

### 6.6.3. Estrategia en Ronda Abierta 

## Estrategia Pasada:

* **Open Challenge Video:**

  <div align="center">
	
  Open Challenge Video (https://youtu.be/WPSj0BXfQ5U)

  *Demuestra navegación autónoma y control de velocidad en una pista dinámica.*

  </div>

* **Estrategia:** Para cumplir con los desafíos del Open Challenge, se diseñó e implementó una arquitectura de software basada en un bucle de control de alta frecuencia. La estrategia central no depende de un solo sensor, sino de un Control Híbrido (Sensor Fusión) que alterna dinámicamente entre la Visión Artificial (cámara) y la Telemetría Acústica (sensores ultrasónicos) según las condiciones de la pista. El sistema se divide en cuatro pilares de ejecución: Detección de Sentido, Control de Trayectoria (PIDs independientes), Navegación en Esquinas y Seguridad Activa (Anticolisión).

* **ROIs:** Para optimizar el procesamiento computacional, mantener un alto framerate y evitar falsos positivos con elementos externos a la pista, el campo de visión de la cámara se segmenta geométricamente:
  * *ROI Principal (Búsqueda de Color):* Un recuadro amplio (0, 50, width, height-100) dedicado exclusivamente a procesar máscaras de color (Rojo, Verde, Azul, Naranja) mediante la búsqueda de contornos.
  * *ROIs Laterales (Centrado Visual):* El espacio inferior se divide en dos cuadrantes simétricos, `roi_izq` y `roi_der`. Estas regiones aplican una máscara negra (`mask_black`) para calcular en tiempo real el área en píxeles de las paredes laterales de la pista, permitiendo que el algoritmo sepa matemáticamente hacia qué lado está más inclinado el chasis.

* **Contador de Loops:** En los instantes iniciales de la carrera, el robot ejecuta ciclos de evaluación (loops de detección) para procesar el área de los colores clave que dictan la dirección del circuito. Si en estos loops el sistema detecta un área mayor a un umbral crítico de 1200 píxeles de color Naranja, la variable de estado asume una orientación de giro a la derecha; si el umbral se rompe con el color Azul, el sistema bloquea la lógica para girar a la izquierda durante el resto de las vueltas.

* **Diagrama de Flujo:**

 <div align="center">

  untitled (1)

 </div>

---

## Estrategia Actual:

* **Open Challenge Video:**

  <div align="center">
	
  (video)

  *Demuestra navegación autónoma y control de velocidad en una pista dinámica.*

  </div>

* **Estrategia Actual:** En esta nueva versión, se migró de un sistema de control híbrido (sensores de ultrasonido + cámara) a un **paradigma de Visión Artificial Pura en C++17** ejecutado a alta frecuencia. Se eliminó la dependencia de la telemetría acústica para evitar conflictos de arbitraje e interrupciones por rebotes de eco en las paredes laterales. El control del chasis y la percepción del entorno se gestionan mediante el procesamiento eficiente de imágenes utilizando **OpenCV con backend GStreamer**, mientras que la respuesta física (servomotor y motor de tracción) se coordina mediante la librería **pigpio**, aprovechando la modulación PWM por Hardware vía DMA para garantizar máxima precisión y nula latencia.

* **ROIs:** Para optimizar el uso de recursos computacionales, mantener un framerate elevado y filtrar falsos positivos externos a la pista, la captura de video se segmenta dinámicamente en **5 zonas de procesamiento estratégico**:

1.  `ROI 1 (Lateral Izquierdo) [0, 40, 320, 160]`: Procesa el área de las paredes oscuras del carril izquierdo (`left_blk`).
    
2.  `ROI 2 (Lateral Derecho) [320, 40, 640, 160]`: Procesa el área de las paredes oscuras del carril derecho (`right_blk`).
    
3.  `ROI 3 (Central Frontal) [200, 20, 430, 200]`: Supervisa la presencia lejana o cercana de la pared frontal (`central_blk`) para determinar la salida de las curvas.
    
4.  `ROI 4 (Inferior de Control) [200, 90, 430, 200]`: Detecta los bloques/marcas de color en el suelo (`down_orange` y `down_blue`) para fijar el sentido de la pista y registrar el conteo de vueltas.
    
5.  `ROI 5 (Central Superior) [200, 70, 430, 140]`: Analiza marcadores de transición lejanos (`central_orange` y `central_blkt`) para anticipar cambios de estado antes de ingresar a la curva.

* **Contador de loops:** Durante la fase inicial de arranque (`ESTADO_CARRERA = "INICIANDO"`), el robot evalúa el color predominante en el suelo mediante el `ROI 4`. Si el área naranja supera el umbral crítico (`down_orange > 1000`), la variable global `turning_direction` asume el valor `2` (Giro en sentido horario / derecha). Si el área azul rompe el umbral (`down_blue > 1000`), se establece en `1` (Giro en sentido antihorario / izquierda). Esta decisión queda bloqueada para el resto del recorrido.

* **Algoritmo de Centrado y Control Proporcional:** El centrado en tramos rectos se basa en la diferencia diferencial del área de pared detectada en ambos lados:

$$\text{Error} = \text{Área}_{\text{Izq}} - \text{Área}_{\text{Der}}$$

$$\text{Ángulo Servo} = 90^\circ + (0.001 \times \text{Error})$$

El ángulo de la dirección se restringe dinámicamente en una ventana de seguridad entre $70^\circ$ y $110^\circ$ para evitar sobrevirajes bruscos en línea recta.

* **Máquina de Estados Finita (FSM) para la Navegación en Curvas:** El sistema se estructura bajo dos estados principales:

1.  **`INICIANDO`:** El motor opera a alta velocidad (PWM `210`) realizando correcciones de centrado proporcional continuo. Al detectar la cercanía de una esquina por color (`down_orange > 500` o `central_orange > 800`), transita inmediatamente al estado de giro.
    
2.  **`GIRANDO`:** El robot reduce la velocidad de tracción (PWM `120`–`140`) y aplica un ángulo de viraje fijo ($80^\circ$ o $110^\circ$). La transición de regreso a `INICIANDO` ocurre de forma autónoma cuando la masa oscura de la pared frontal desaparece del campo visual (`central_blk < 9500` o `< 8400`), reanudando la aceleración en el carril recto.

* **Conteo de Vueltas y Apagado Seguros (Garantía de 12 Vueltas):**  Se implementó un control de histeresis (`transicion`) que incrementa la variable `loops` únicamente cuando el robot ejecuta una curva en presencia de la marca oficial de la pista.
    
-   **Finalización de Carrera:** Al alcanzar la vuelta 12 (`loops == 12`), el sistema inicia un temporizador de precisión mediante `std::chrono::steady_clock`. Tras avanzar $3.5$ segundos adicionales para asegurar que el chasis cruce completamente la línea de meta, el programa interrumpe el bucle principal.
    
-   **Seguridad Hardware:** Mediante el gestor de señales `gpioSetSignalFunc(SIGINT)`, ante cualquier parada de emergencia o Ctrl+C, se ejecutan de forma asíncrona y segura la detención del motor (`PI_LOW`), el corte de señal PWM del servomotor y la liberación limpia del demonio `pigpio`.

---

### 6.6.4. Estrategia en Ronda de Obstaculos 

## Estrategia Pasada:

* **Estrategia:** La estrategia diseñada para abordar el segundo reto (evasión de obstáculos) se construye de forma modular sobre la base arquitectónica de la ronda abierta. Se conservan las Regiones de Interés laterales (`roi_izq` y `roi_der`), la resolución de la cámara y los filtros de segmentación de color base.
El núcleo de este reto radica en la interpretación semántica del entorno según las reglas oficiales de la competencia: los pilares actúan como señales direccionales que indican el carril de paso correcto. Para cumplir con esta lógica de navegación de manera robusta a una velocidad constante (`VELOCIDAD_BASE = 68`), el software se estructuró sobre tres pilares fundamentales:

1. Base del Reto Abierto (Navegación Línea Base): Conserva el control de centrado mediante la diferencia de áreas de líneas y el fallback de seguridad asistido por ultrasonidos.
2. Técnica de Selección de Carril (Visión Computacional): Segmentación por color a larga distancia mediante una nueva Región de Interés frontal expandida (`ROI_OBSTACULOS`).
3. Máquina de Estados Asíncrona: Algoritmos de control dedicados para la evasión precisa y el retorno seguro al carril.

*Para anticipar la trayectoria de los pilares sin interferir con la lectura de las líneas guía del suelo, se implementó una zona de escaneo central denominada `ROI_OBSTACULOS` con dimensiones optimizadas en píxeles ROI(30, 30, 610, 320). Esta configuración permite procesar los objetos antes de que entren en el umbral crítico de colisión frontal.*

Adicionalmente, el sistema implementa dos lazos de control PID independientes con sintonizaciones diferenciadas según las necesidades dinámicas del vehículo:

* **PID de Línea Estándar:** Configurado con valores conservadores ($K_p = 0.015, K_d = 0.035$) para mantener transiciones suaves y un desplazamiento lineal estable en rectas.

* **PID de Evasión de Obstáculos:** Configurado con una respuesta altamente agresiva ($K_p = 0.32, K_d = 0.01$). El término proporcional elevado garantiza que el vehículo responda con un torque de dirección inmediato ante el desplazamiento del pilar en la imagen, mientras que el término derivativo amortigua el retorno para evitar que la parte trasera del chasis (cola) derrape y golpee el obstáculo.

**Implementación de la Máquina de Estados de Navegación:** El comportamiento dinámico de Halbi the Green se rige por una máquina de estados finitos que conmuta de forma asíncrona entre tres modos de operación para asegurar que las lógicas de centrado y evasión no entren en conflicto.

1. **Estado 1: LINEAL (Navegación Base y Curvas Cerradas)**
  Es el estado por defecto del robot. Mientras se encuentra en este modo, el vehículo ejecuta de forma prioritaria el centrado geométrico calculando el error entre las áreas negras laterales (`error = black_areas[1] - black_areas[0]`). Si el sensor de ultrasonido frontal detecta una pared a corta distancia (`front_dist < 90 cm`) en copresencia con una alta densidad de pixeles negros de pista (`LNM.black_area > 8000`), el estado se bloquea temporalmente bajo la bandera `girando = True` para forzar un giro de esquina cerrada de 90°. De manera simultánea, el método `procesar_obstaculos()` analiza los contornos máximos filtrados bajo las máscaras `mask_red` y `mask_green`. La transición hacia el estado de evasión se activa inmediatamente cuando el área de un contorno supera los umbrales de ruido calibrados:
  * **Pilar Verde:** Área $> 350 \text{ px} \rightarrow$ Transición a ESQUIVANDO | `memoria_lado = "IZQUIERDA"` (El pilar se debe dejar a la izquierda).
  * **Pilar Rojo:** Área $> 300 \text{ px} \rightarrow$ Transición a ESQUIVANDO | `memoria_lado = "DERECHA"` (El pilar se debe dejar a la derecha).

2. **Estado 2: ESQUIVANDO (Lazo de Control de Evasión)**
  Al entrar en este modo, el PID de líneas se suspende y el control de dirección pasa al lazo PID de obstáculos. El algoritmo persigue un Setpoint o punto de consigna absoluto en los extremos del cuadro visual para forzar al carro a abrirse hacia el carril libre:
  * Para pilares verdes (dejar a la izquierda), se busca el `SETPOINT_VERDE = 549` (extremo derecho del marco).
  * Para pilares rojos (dejar a la derecha), se busca el `SETPOINT_ROJO = 50` (extremo izquierdo del marco).

  *Mecanismo de Tiempo de Gracia:* Debido a la agresividad del giro, es común que el pilar salga del campo visual de la cámara antes de que el vehículo lo haya superado físicamente. Para evitar que el robot regrese prematuramente al centro de la pista y colisione con el obstáculo, se implementó un temporizador de inercia (`TIEMPO_GRACIA = 0.2` segundos). Si el área del pilar cae a cero, el sistema mantiene el cálculo del último error registrado (`error_obs = prev_error`), sosteniendo el ángulo de giro por hardware durante el tiempo de gracia antes de conmutar al estado REBASANDO.

  *Seguridad por Encajonamiento:* Si los sensores ultrasónicos detectan que el vehículo se está aproximando peligrosamente a la pared exterior del circuito debido a la maniobra de esquiva (`left_dist` o `right_dist < DIST_MIN_PARED` de $18.0\text{ cm}$), la máquina aborta el lazo PID de visión y fuerza la transición inmediata al estado de rebase para proteger la integridad estructural.

3. **Estado 3: REBASANDO (Zona de Seguridad y Retorno)**
  Este estado garantiza que la parte posterior del chasis rebase completamente el pilar antes de restablecer las condiciones de carrera lineal. Dado que la cámara ya no posee contacto visual con el obstáculo, el control se delega a la telemetría de los sensores ultrasónicos laterales. El vehículo mantiene un ángulo de compensación controlado según el lado memorizado para evitar rozar la pared lateral. La máquina de estados no permite el regreso al modo LINEAL hasta que el sensor de ultrasonido del lado opuesto al pilar registre una distancia libre mayor a $40\text{ cm}$ (`left_dist > 40` o `right_dist > 40`). Esta holgura asegura de forma matemática que el volumen total del robot ha despejado la posición del pilar, evitando enganches con las esquinas traseras o la base del obstáculo.

Como última capa de protección ante pérdidas de tracking visual o escenarios de colisión inminente, el ciclo de control ejecuta en cada iteración una subrutina de freno de mano físico. Si el ultrasonido frontal registra una distancia menor a `DIST_MIN_CHOQUE` ($12.0\text{ cm}$), el vehículo interrumpe la energía de los motores mediante `LNM.stop()` y calcula un ángulo de escape inverso de manera dinámica:

<div align="center">

$$\text{Ángulo Escapatoria} = 160^\circ - \text{steering}_{\text{angle}}$$

</div>

El robot realiza una maniobra de retroceso a alta potencia (`speed = 85`) durante $0.75$ segundos, resetea las variables integrales del PID a cero y reestablece el estado de carrera a LINEAL, garantizando la resiliencia del software ante condiciones críticas de atasco ambiental.

#### Diagrama de Flujo:

<div align="center">



</div>

---

## Estrategia Actual:

* **Obstacle Challenge Video:**

  <div align="center">
	
  (Video)

  *Demuestra navegación autónoma, control de velocidad y esquiva de obstáculos en una pista dinámica.*

  </div>

* **Estrategia:** Elimina por completo la dependencia acústica de los ultrasonidos para la evasión. Implementa un **Control PD Dinámico Ponderado por Área (Proximidad)** apoyado en un filtro de **Histéresis por Conteo de Frames (Memoria Visual)** ejecutado a alta velocidad mediante GStreamer + OpenCV.

* **Matriz Comparativa de Arquitectura:**

| Parámetro / Componente | Estrategia Pasada | Estrategia Actual |
| --- | --- | ---|
|Sensores de Evasión | Cámara OpenCV + Ultrasonidos laterales y frontales. | Cámara de alta velocidad + Pipeline GStreamer (Sin ultrasonidos). |
| Lógica de Esquive | PID agresivo fijo a setpoints laterales estáticos. | PD Ponderado por área de proximidad ($\text{Peso} \in [0.0, 1.0]$). |
| Retorno al Carril | Telemetría ultrasónica lateral ($d > 40\text{ cm}$). | Filtro de Histéresis por conteo de frames (8 frames de memoria). |
| Gestión de Velocidad | Velocidad constante (`68`) con frenado brusco. | Velocidad Adaptativa Dinámica: frena de `200` a `140` PWM según cercanía. |

* **ROIs:** **ROI 6 (General Frontal/Obstáculos) `[10, 50, 630, 300]`:** Cubre casi la totalidad del ancho y la sección superior del marco visual. Permite detectar contornos de pilares **Rojos** y **Verdes** a larga distancia antes de que entren al carril de paso.

* **Control PD Ponderado por Proximidad y Velocidad Adaptativa:** En lugar de virar de forma brusca al avistar un pilar, el sistema ajusta la corrección mediante un **Factor de Peso ($\text{Peso}$)** que depende del área del objeto en píxeles:

-   **Cálculo del Factor de Peso:**
    
    $$\text{Área Útil} = \max\left(0.0, \text{Área Central} - \text{Umbral}\right)$$
    
    _(Umbral Rojo: $900\text{ px}$ | Umbral Verde: $2200\text{ px}$)_
    
    $$\text{Peso} = \min\left(1.0, \frac{\text{Área Útil}}{2500.0}\right)$$
    
-   **Corrección de Dirección Ponderada:**
    
    $$\text{Corrección} = \text{Peso} \cdot \left[ (K_p \cdot \text{Error}) + (K_d \cdot \text{Derivada}) \right]$$
    
-   **Control de Modulación de Velocidad:**
    
    $$\text{Velocidad Motor} = 200 - (\text{Peso} \cdot 60)$$
    
    _(Modula linealmente entre 200 PWM cuando está lejos y 140 PWM al estar muy cerca)_

**Parámetros por Color:**

1.   **Pilar Rojo (Dejar a la Derecha):** Target en `SetPoint_Red = 60` con $K_p = 0.40$ y $K_d = 0.15$.
    
2.   **Pilar Verde (Dejar a la Izquierda):** Target en `SetPoint_Green = 584` con $K_p = 0.01$ y $K_d = 0.00$.

* **Memoria de Histéresis Visual (Salida Segura de Obstáculo):** Para evitar que el chasis golpee el pilar cuando este sale del campo de visión antes de superarlo físicamente:

1.  **Activación:** Se enciende `modo_esquive_activo` al superar el umbral de área y se memoriza el color en `ultimo_obstaculo_fue_rojo`.
    
2.  **Pérdida Visual:** Si el pilar desaparece del encuadre, el contador `frames_sin_obstaculo` comienza a incrementarse en cada ciclo.
    
3.  **Retorno Seguro:** Se mantiene el viraje de evasión durante **8 frames consecutivos** (~0.3 a 0.4 segundos). Transcurrido este tiempo, el sistema desactiva el esquive y retorna al centrado lineal del carril libre.

---

## 7. Problemas y soluciones durante el desarollo 

### Problemas de Hardware:

**Objetivo:** Completar tres vueltas de forma autónoma en circuitos configurados dinámicamente.

#### Problemas de espaciamiento

Durante el desarrollo temprano de *Halbi the Green*, se presentaron inconvenientes con respecto al posicionamiento de los componentes dentro del chasis base (sin modificar). Debido a que los componentes ocupaban más espacio del disponible, el problema se resolvió temporalmente fijándolos con cinta aislante. Aunque esto funcionó de forma provisional, no era una solución viable a largo plazo. 

Por ello, se decidió implementar una serie de bases impresas en 3D pensadas para agregar **dos niveles adicionales** al vehículo y **tres soportes complementarios** (dos laterales y uno frontal) para ubicar los sensores de ultrasonido, los cuales originalmente no tenían un lugar asignado.

De manera más específica, los problemas de espaciamiento y sus respectivas soluciones fueron los siguientes:

* **Espacio ocupado por las baterías:**
  * *Problema:* Ocupaban demasiado volumen en el chasis y no dejaban espacio para ubicar los componentes de forma cómoda.
  * *Solución:* Se les diseñó una base a medida para ubicarlas en el centro del robot y, sobre esta estructura, se construyó el piso superior.

* **Anclaje de sensores de ultrasonido:**
  * *Problema:* No tenían puntos previstos para anclarlos al chasis original.
  * *Solución:* Se diseñaron 3 bases impresas que van adjuntas a 3 caras del chasis.
  * *Nota técnica:* Esta solución no fue del todo ideal, ya que estas bases sobresalen un poco de la estructura, causando atascamientos mecánicos cuando el vehículo pasa muy cerca de una esquina.

* **Ubicación de la cámara y controlador:**
  * *Problema:* No había lugar físico para situar la cámara ni la placa de procesamiento.
  * *Solución:* Sobre la base de las baterías se diseñó un soporte dedicado para la Raspberry Pi y la cámara. Esta última incluye una base con ángulo graduable para poder ajustar el punto de vista del lente de manera cómoda y precisa.

## 8. **Licencia y réplica** 

### **Filosofía de código abierto para el avance de la comunidad**

**Documentación centrada en la réplica**:
- **Transparencia técnica total**: Se documentan todas las decisiones de diseño y los detalles de implementación
- **Accesibilidad en la fabricación**: Uso de componentes ampliamente disponibles y métodos de fabricación personalizados
- **Valor educativo**: Explicaciones detalladas que permiten comprender los principios de ingeniería
- **Desarrollo futuro**: Vías claras para mejoras y modificaciones del sistema

Este proyecto está licenciado bajo la **Licencia Pública General Affero de GNU v3.0 (AGPL-3.0)** para promover la colaboración abierta, garantizar el acceso continuo de la comunidad a obras derivadas, facilitar la réplica por parte de futuros desarrolladores y equipos de competencia, y fomentar la innovación continua a través de desarrollos de acceso público.

```
Licencia Pública General Affero de GNU v3.0

Copyright (C) 2026 Pdddro28 (Pedro Catamo)

Este programa es software libre: puedes redistribuirlo y/o modificarlo
bajo los términos de la Licencia Pública General Affero de GNU tal como la publicó
la Fundación para el Software Libre, ya sea la versión 3 de la Licencia o
(a tu elección) cualquier versión posterior.

Este programa se distribuye con la esperanza de que sea útil,
pero SIN NINGUNA GARANTÍA; ni siquiera la garantía implícita de
COMERCIABILIDAD o IDONEIDAD PARA UN PROPÓSITO PARTICULAR. Consulte la
Licencia Pública General Affero de GNU para obtener más detalles.

Debería haber recibido una copia de la Licencia Pública General Affero de GNU
junto con este programa. De no ser así, consulte <https://www.gnu.org/licenses/>.
```

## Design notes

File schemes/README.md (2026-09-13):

# Schemes 
En esta carpeta se encuentra el diagrama de cableado y diagramas de flujo.

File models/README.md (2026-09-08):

### 3D Printed Components & Attachments

During the development of the vehicle, structural space constraints on the stock chassis made it unfeasible to mount all electronic and mechanical components directly to the base plate. To maximize spatial efficiency and maintain a low center of gravity, we designed and 3D-printed several custom modular attachments. These components extend the chassis vertically and provide secure, vibration-resistant housings for our specialized hardware.

**Halbi The Green 3d Models:**
---

<div align="center">

| Component & Preview | Design & Geometry | Engineering Purpose |
|---|---|---|
| **Base** <br><br> | Diseñado como una jaula de torre vertical estructurada con cuatro pilares reforzados en cada lado, integrada directamente sobre una base de montaje sólida con ojales para tornillos en las esquinas. Las paredes laterales cuentan con grandes recortes circulares para minimizar el peso del material mientras permiten un flujo de aire pasivo máximo para evitar el estrés térmico en las celdas LiPo durante altas tasas de descarga. El pilar superior incluye ojales de retención ranurados para una sujeción segura de las correas. | Centraliza la masa combinada de las celdas de la batería verticalmente a lo largo del eje geométrico central del chasis. Este diseño de jaula abierta garantiza un acceso rápido para el reemplazo de la batería entre carreras, al tiempo que proporciona una contención estructural rígida contra las fuerzas de inercia laterales durante giros a alta velocidad. |
| **Camera Case** <br><br> | Una carcasa protectora rectangular y compacta, diseñada específicamente para encapsular el sensor IMX219 (Arducam). Esta es la base de la camara, es una base de angulo fijo y elevada a la altura del robot | Esta se decidio dejar con un angulo fijo debido a que a lo largo del uso del 1er prototipo de carro para FE 2026 ("Halbi the green") nos dimos cuenta que ese era el angulo que mejor nos funcionaba para visualizar la pista desde el punto de vista del robot. |
| **Battery Case Holder** <br><br> | Una bandeja robusta de perfil bajo equipada con cuatro soportes verticales integrados de alta resistencia posicionados en las esquinas para asegurar el PCB principal. La placa base cuenta con guías de distribución internas y cortes de holgura estructural para evitar los componentes en la parte inferior de la placa, manteniendo el perfil lo más cercano posible al chasis. | Funciona como una cuna mecánica rígida para la electrónica de potencia de bajo nivel. Al elevar el PCB mediante los soportes integrados de 3 mm, evita cortocircuitos eléctricos con el chasis al tiempo que amortigua las vibraciones. El perímetro completamente abierto garantiza el acceso inmediato a los terminales de tornillo del motor, los rieles de alimentación y los puertos de sensores para el mantenimiento en campo. |
| **Rim** <br><br> | Una plataforma modular plana de nivel medio que cuenta con cuatro soportes de esquina integrados para montar la Raspberry Pi 4 de forma segura. La sección frontal de la base integra un montaje de bisagra de doble oreja equipado con dientes de bloqueo internos que se acoplan directamente con la bisagra de la carcasa de la cámara (Camera Case). | Sirve como un puente estructural de doble propósito. Proporciona un montaje estable y elevado para la computadora de a bordo de alto nivel, asegurando una disipación óptima del calor a través de la convección natural para evitar el estrangulamiento térmico del CPU. Al mismo tiempo, su montaje engranado integrado bloquea firmemente el ensamblaje de la cámara en la parte delantera, eliminando la necesidad de componentes adicionales y ahorrando valioso espacio en el chasis.|
| **Motor DC Case** <br><br> | Un soporte protector compacto de doble barril hecho a medida para encapsular firmemente los cilindros del transmisor y receptor del módulo del sensor ultrasónico. Cuenta con pestañas de montaje traseras integradas y bridas inferiores para un acoplamiento mecánico continuo a las vigas transversales delanteras de la estructura del chasis. | Proporciona una carcasa rígida y aislada de vibraciones que mantiene el sensor ultrasónico perfectamente perpendicular al plano horizontal de la pista. Esta alineación precisa elimina la distorsión de la señal acústica y la dispersión de las ondas, garantizando mediciones de distancia en tiempo real altamente precisas para la detección de obstáculos y mapas de frenado de emergencia. |
| **Direccional** <br><br> | Un soporte protector compacto de doble barril hecho a medida para encapsular firmemente los cilindros del transmisor y receptor del módulo del sensor ultrasónico. Cuenta con pestañas de montaje traseras integradas y bridas inferiores para un acoplamiento mecánico continuo a las vigas transversales delanteras de la estructura del chasis. | Proporciona una carcasa rígida y aislada de vibraciones que mantiene el sensor ultrasónico perfectamente perpendicular al plano horizontal de la pista. Esta alineación precisa elimina la distorsión de la señal acústica y la dispersión de las ondas, garantizando mediciones de distancia en tiempo real altamente precisas para la detección de obstáculos y mapas de frenado de emergencia. |
| **Triangulo Ackermann** <br><br> | Un soporte protector compacto de doble barril hecho a medida para encapsular firmemente los cilindros del transmisor y receptor del módulo del sensor ultrasónico. Cuenta con pestañas de montaje traseras integradas y bridas inferiores para un acoplamiento mecánico continuo a las vigas transversales delanteras de la estructura del chasis. | Proporciona una carcasa rígida y aislada de vibraciones que mantiene el sensor ultrasónico perfectamente perpendicular al plano horizontal de la pista. Esta alineación precisa elimina la distorsión de la señal acústica y la dispersión de las ondas, garantizando mediciones de distancia en tiempo real altamente precisas para la detección de obstáculos y mapas de frenado de emergencia. |
| **Pillar** <br><br> | Un soporte protector compacto de doble barril hecho a medida para encapsular firmemente los cilindros del transmisor y receptor del módulo del sensor ultrasónico. Cuenta con pestañas de montaje traseras integradas y bridas inferiores para un acoplamiento mecánico continuo a las vigas transversales delanteras de la estructura del chasis. | Proporciona una carcasa rígida y aislada de vibraciones que mantiene el sensor ultrasónico perfectamente perpendicular al plano horizontal de la pista. Esta alineación precisa elimina la distorsión de la señal acústica y la dispersión de las ondas, garantizando mediciones de distancia en tiempo real altamente precisas para la detección de obstáculos y mapas de frenado de emergencia. |

</div>

---

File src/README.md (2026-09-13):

# Source Code

En esta carpeta se encuentra el código principal de nuestro robot

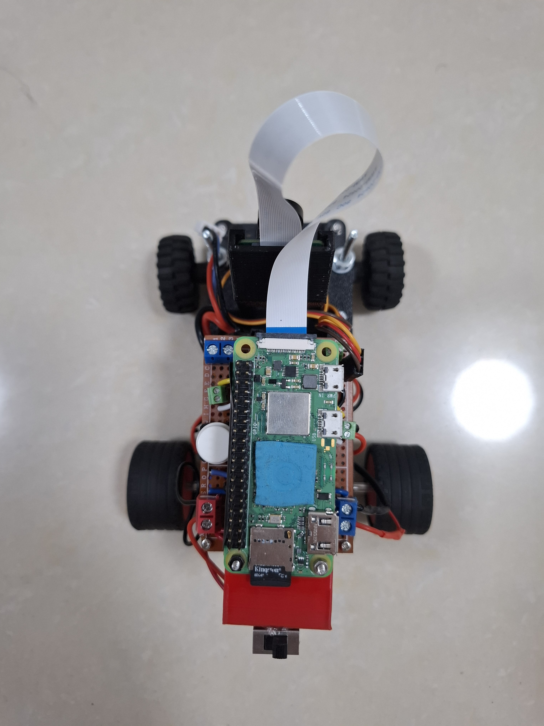
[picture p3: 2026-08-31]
v-photos/Upper-view.jpg

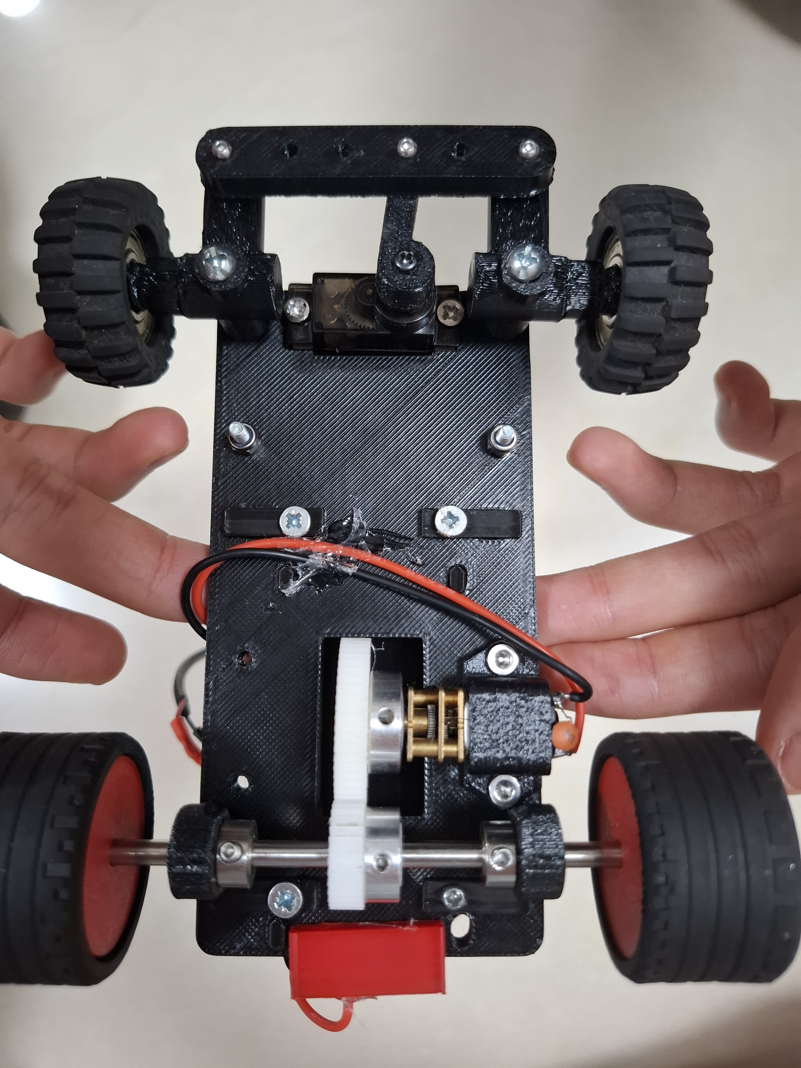
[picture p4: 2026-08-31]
v-photos/Bottom-view.jpg

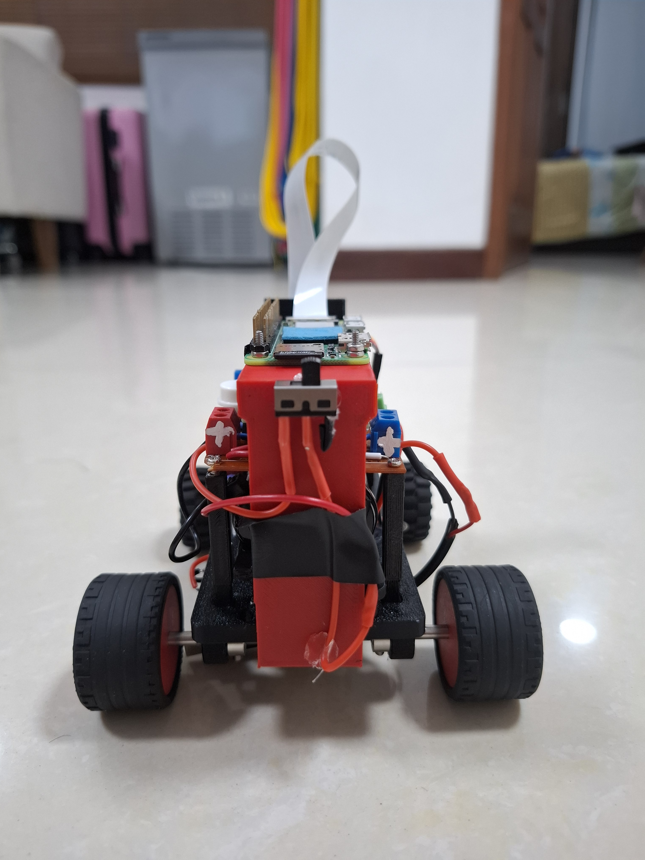
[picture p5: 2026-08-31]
v-photos/Back-view.jpg

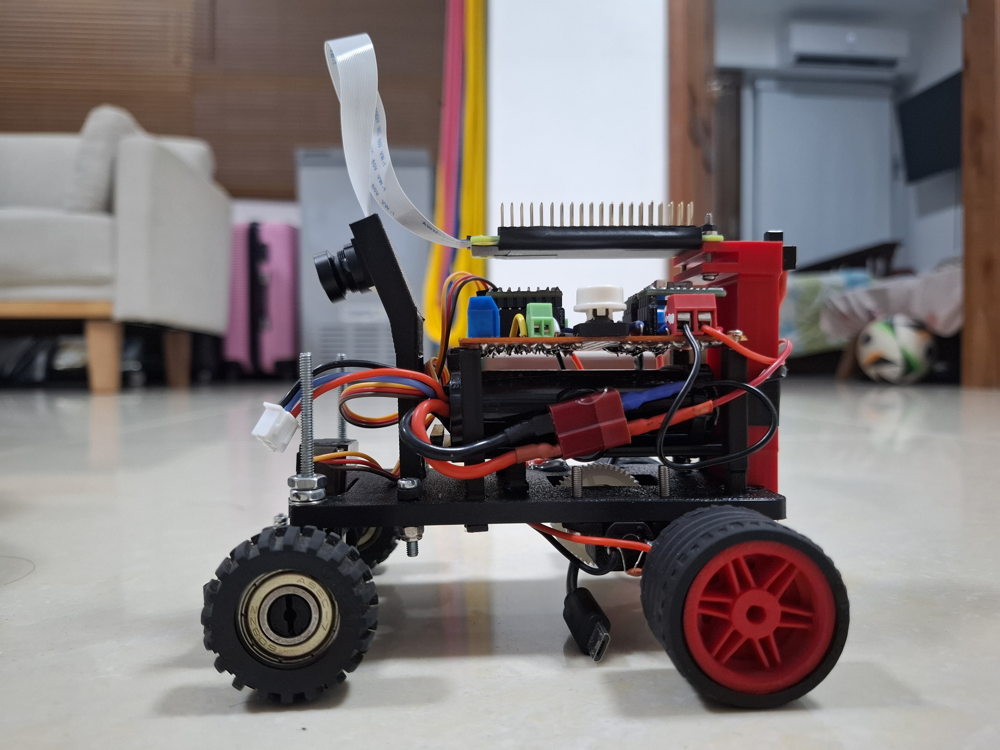
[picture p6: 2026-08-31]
v-photos/Left-view.jpg

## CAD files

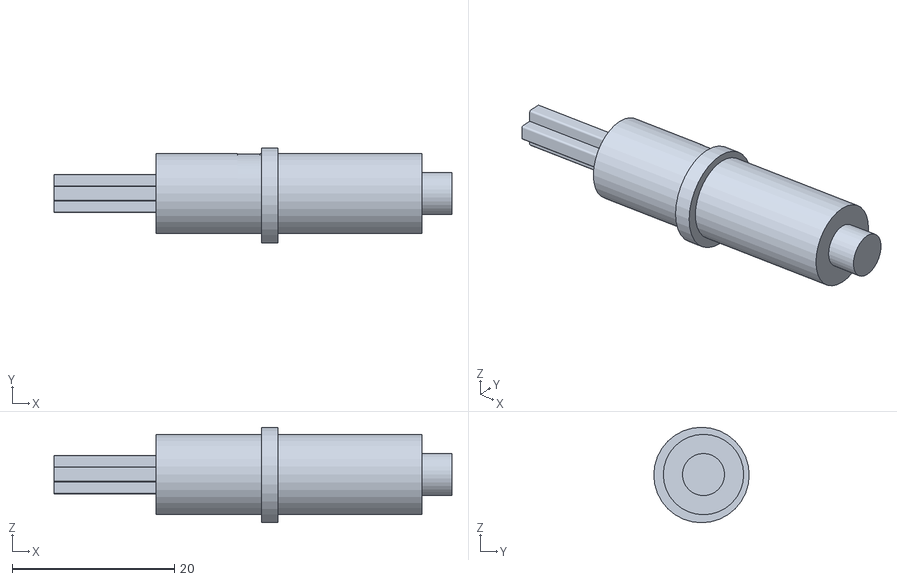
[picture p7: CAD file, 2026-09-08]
models/Ing eje 01.stl
49.0 x 11.8 x 11.8

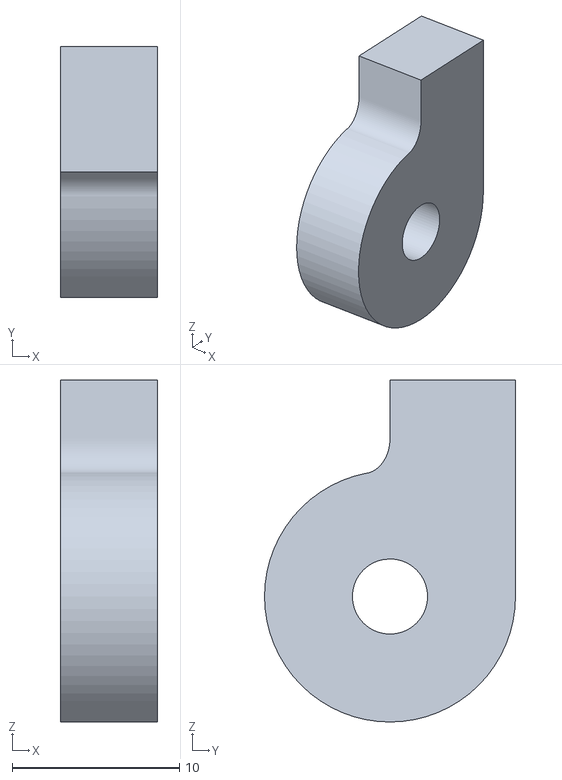
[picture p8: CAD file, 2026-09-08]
models/Ing SOP NEW EJE .stl
5.81 x 15.0 x 20.4

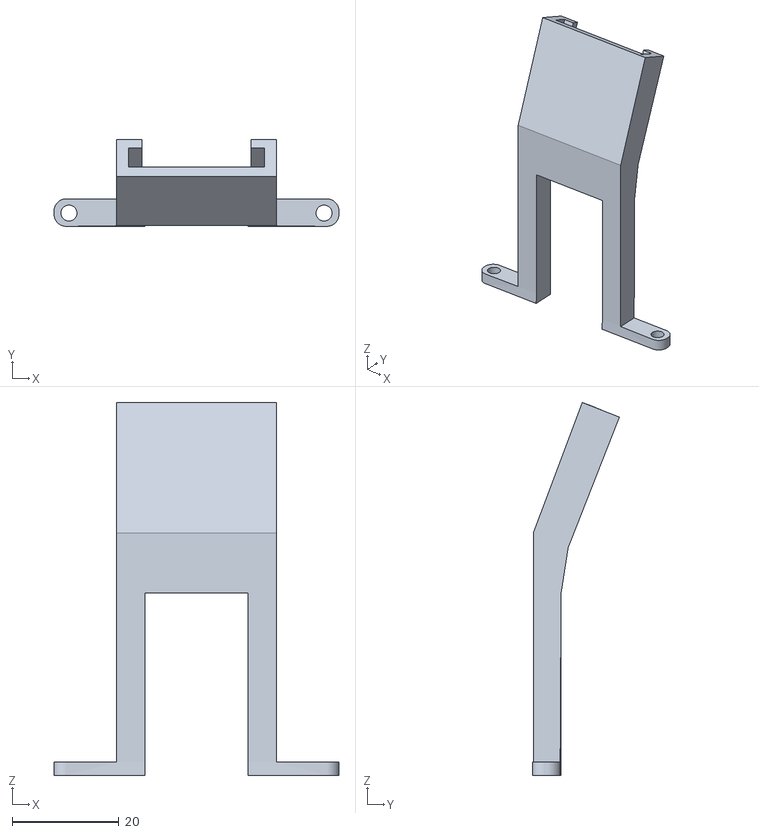
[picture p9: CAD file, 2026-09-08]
models/ing SOP CAM .stl
53.5 x 16.3 x 70.0

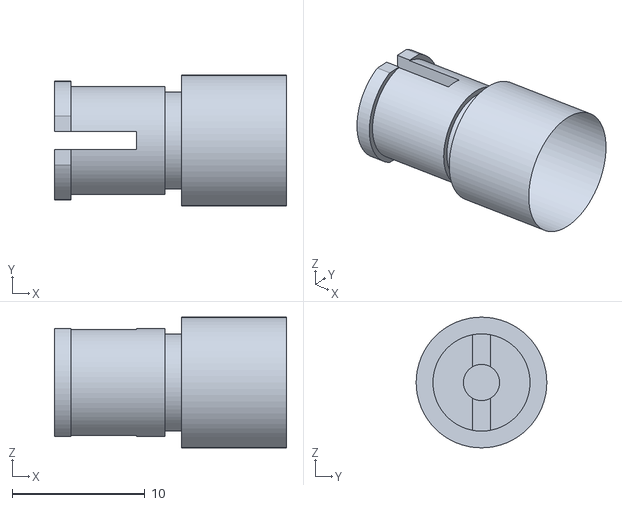
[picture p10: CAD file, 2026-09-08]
models/Ing PIN WHEEL.stl
17.5 x 9.85 x 9.85

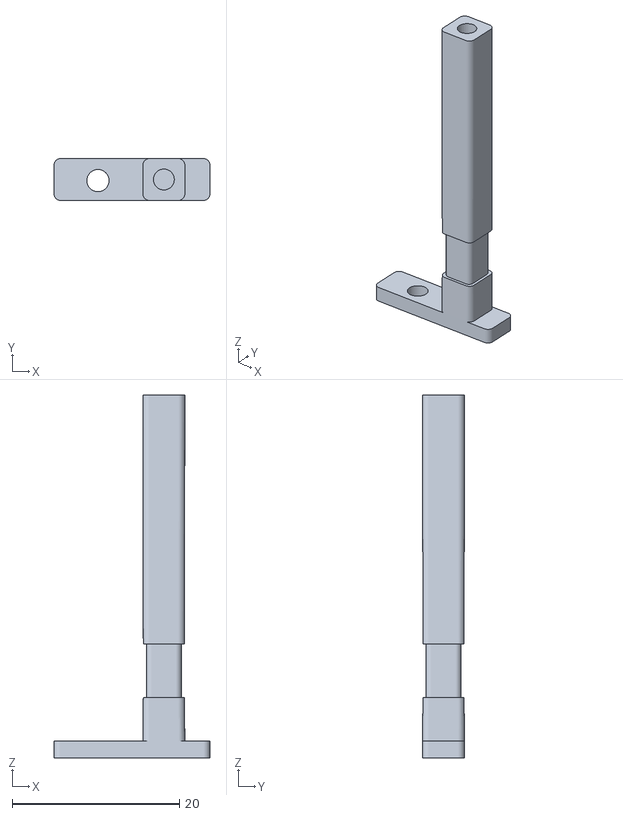
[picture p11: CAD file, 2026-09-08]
models/ing tall PIN 1.stl
18.6 x 5.00 x 43.4

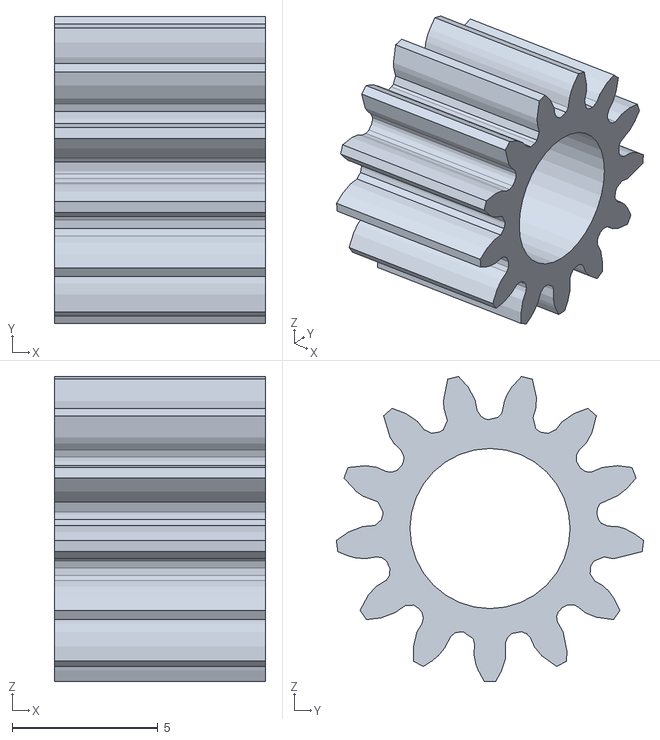
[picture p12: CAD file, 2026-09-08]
models/Ing eje DIF.stl
7.25 x 10.6 x 10.5

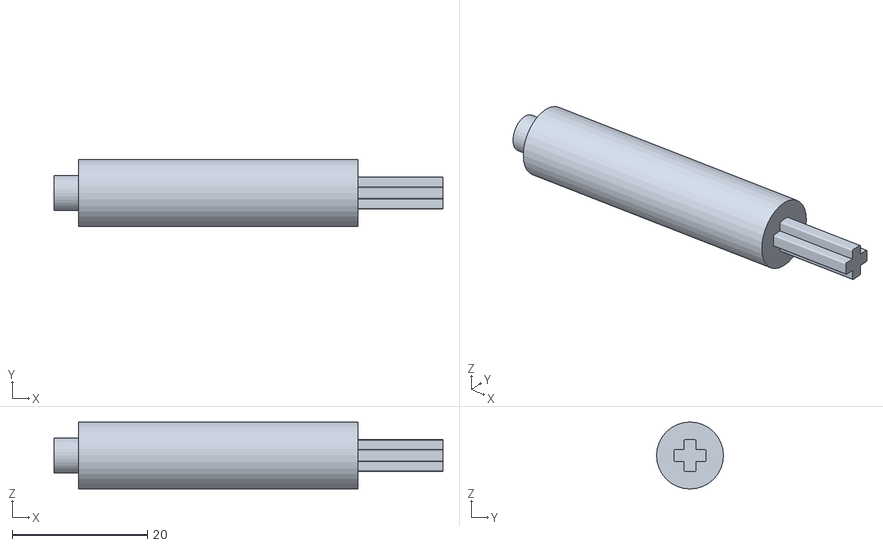
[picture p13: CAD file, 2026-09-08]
models/Ing eje 02.stl
57.5 x 9.90 x 9.90

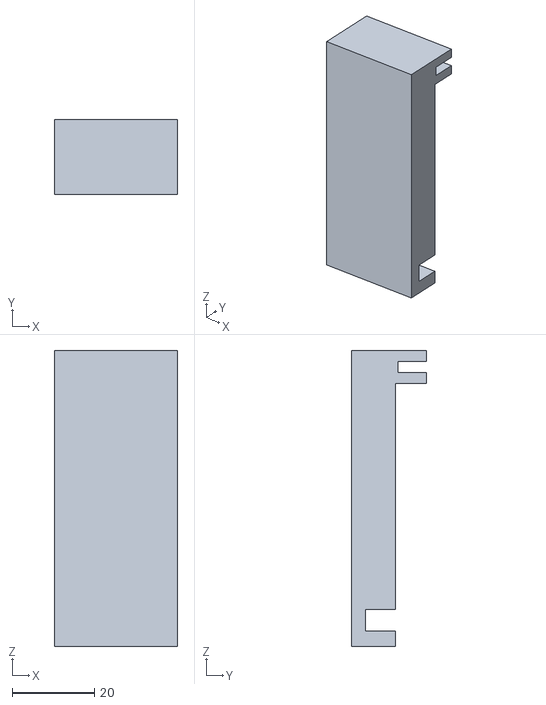
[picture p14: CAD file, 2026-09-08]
models/Ing SOP TOP.stl
30.0 x 18.1 x 72.0

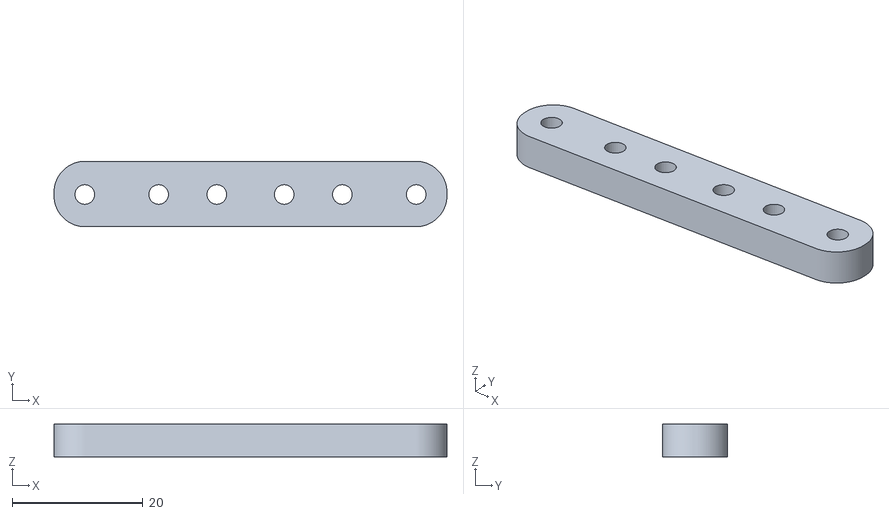
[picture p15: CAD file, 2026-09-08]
models/ing akerman 2.stl
60.0 x 10.0 x 5.00

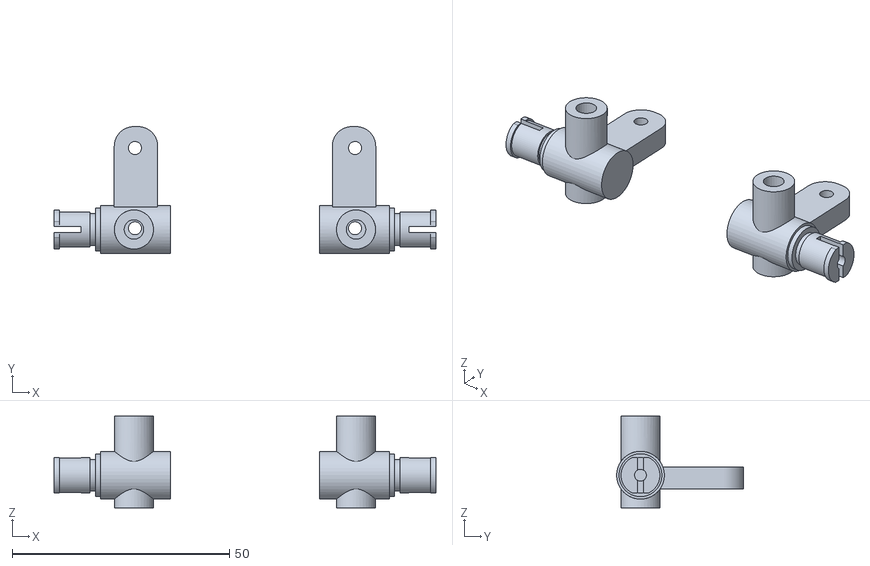
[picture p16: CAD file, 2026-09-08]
models/ing akerman 1.stl
87.8 x 29.2 x 21.1

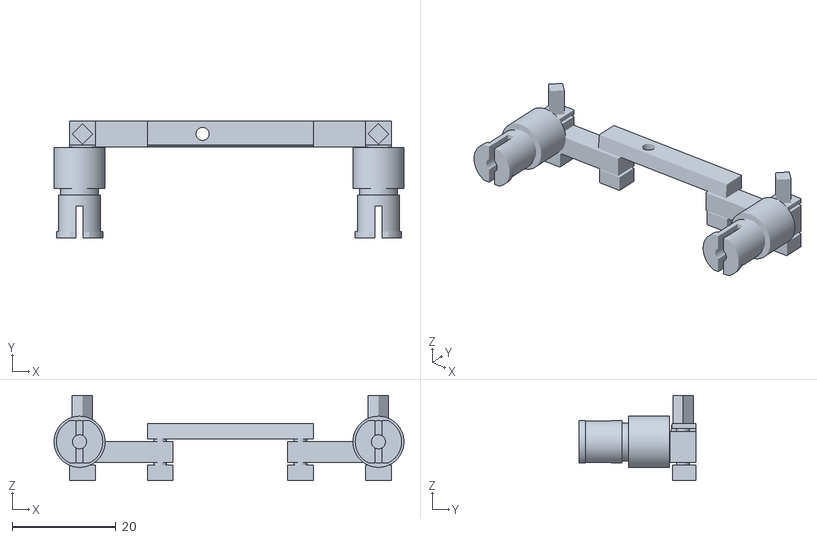
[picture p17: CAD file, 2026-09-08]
models/ing akerman .stl
67.4 x 22.6 x 16.4

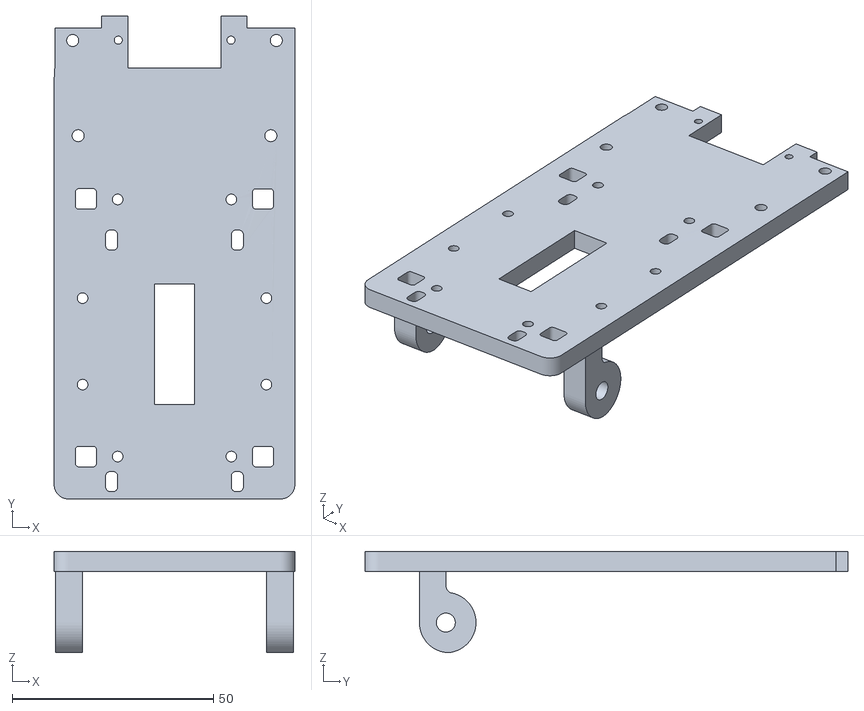
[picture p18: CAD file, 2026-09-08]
models/Chasis Ing_05.stl
59.8 x 120.0 x 25.2

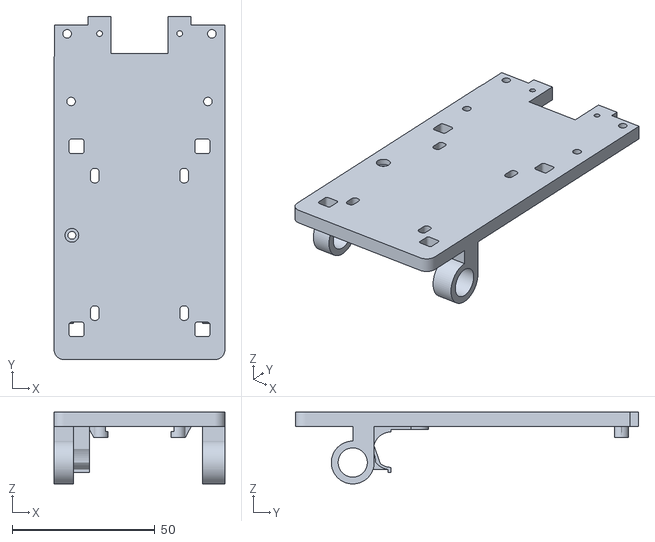
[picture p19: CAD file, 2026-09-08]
models/Chasis Ing_03.stl
59.8 x 120.0 x 25.2

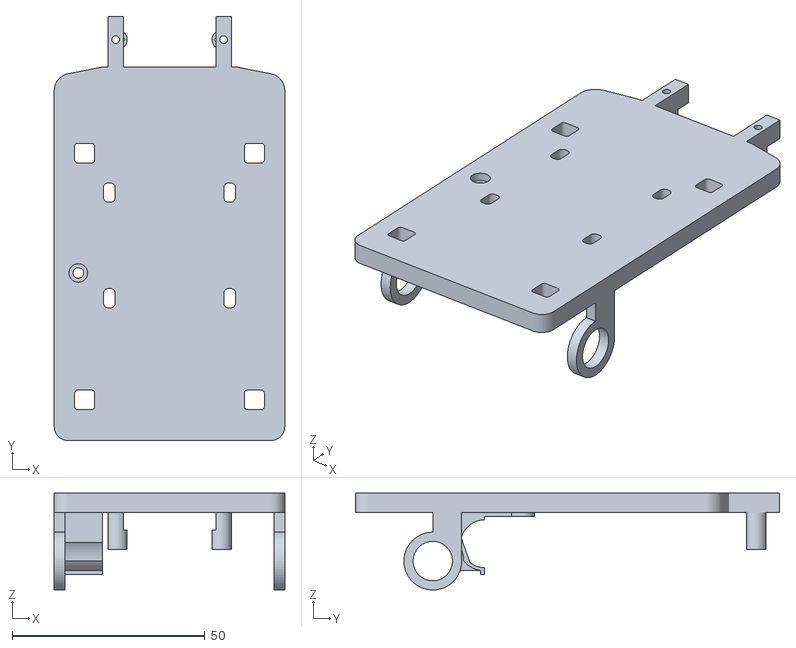
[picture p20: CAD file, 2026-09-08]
models/Chasis Ing_01.stl
59.8 x 110.0 x 25.2

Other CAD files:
models/Chasis Ing_02.stl
models/Chasis Ing_04.stl
models/Chasis Ing_06.stl
models/ing BAT SOP.stl
models/Chasis Ing_07.stl
models/ing SERVO ARM.stl
models/ing akerman 3.stl
models/ing tall PIN .stl
models/motor clip .stl

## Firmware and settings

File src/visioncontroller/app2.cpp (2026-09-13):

#include "vision_controller.h"
#include <iostream>
#include <pigpio.h>
#include <chrono>
#include <thread>
#include <csignal>
#include <atomic>
#include <string>
#include <cmath>

// Pines GPIO (BCM)
const int SERVO_PIN = 18; // Hardware PWM vía DMA de pigpio
const int MOTOR_IN1 = 19; // GPIO Digital (DRV8833)
const int MOTOR_IN2 = 13; // GPIO Digital (DRV8833)
const int BUTTON_PIN = 25; // GPIO Boton

// Bandera atómica: segura para modificarse dentro de una interrupción
std::atomic<bool> ejecutando(true);

VisionController vision(CameraBackend::GSTREAMER); 

ROI roi1 = {0, 40, 320, 160}; // ROI lateral izquierdo
ROI roi2 = {320, 40, 640, 160}; // ROI lateral derecho
ROI roi3 = {200, 20, 430, 200}; // ROI central
ROI roi4 = {200, 90, 430, 200}; // ROI inferior
ROI roi5 = {200, 70, 430, 140}; // ROI superior naranja
ROI roi6 = {10, 50, 630, 300}; // ROI superior general

enum class Sentido { PARAR, ADELANTE, ATRAS };

// Función de interrupción asíncrona sin operaciones de I/O (std::cout eliminado)
void capturar_ctrl_c(int senal) {
    ejecutando = false;
}

// Mueve el servo en su rango real útil (500us - 2500us)
void mover_servo(int angulo) {
    if (angulo < 0) angulo = 0;
    if (angulo > 180) angulo = 180;

    int pulso_us = 500 + (angulo * 2500 / 180);
    gpioServo(SERVO_PIN, pulso_us);
}

// Estados del motor
void mover_motor(Sentido direccion, int vel) {
    if (direccion == Sentido::ADELANTE) {
        gpioPWM(MOTOR_IN1, vel);
        gpioWrite(MOTOR_IN2, PI_LOW);
    } else if (direccion == Sentido::ATRAS) {
        gpioWrite(MOTOR_IN1, PI_LOW);
        gpioPWM(MOTOR_IN2, vel);
    } else { // PARAR (freno / desconexión)
        gpioWrite(MOTOR_IN1, PI_LOW);
        gpioWrite(MOTOR_IN2, PI_LOW);
    }
}

// Pausa que responde al instante si se presiona Ctrl + C
void pausa_segura(int milisegundos) {
    int pasos = milisegundos / 50;
    for (int i = 0; i < pasos && ejecutando; ++i) {
        std::this_thread::sleep_for(std::chrono::milliseconds(50));
    }
}

// Cronometro
std::chrono::steady_clock::time_point LastTimeDetected;

std::vector<std::pair<int, cv::Mat>> get_color_area(ROI roi, const cv::Mat& frame, const std::vector<std::vector<int>>& range_colors) {
    if (frame.empty()) return {};
    cv::Mat roi_frame = frame(cv::Rect(roi.x1, roi.y1, roi.x2 - roi.x1, roi.y2 - roi.y1));
    
    auto color_contours = vision.find_contours(range_colors, roi);
    auto max_contour_result = vision.max_contour(color_contours, roi);
    
    if (max_contour_result.empty()) return {};
    return max_contour_result;
}

// Color Detector
int left_blk = 0;
int right_blk = 0;
int central_blk = 0;
int down_blue = 0;
int down_orange = 0;
int central_orange = 0;
int central_blkt = 0;
int central_red_area = 0;
int central_red_X = 0;
int central_green_area = 0;
int central_green_X = 0;

std::vector<std::pair<int, cv::Mat>> red_data;
std::vector<std::pair<int, cv::Mat>> green_data;

// Others
int turning_direction = 0;
int frame_count = 0;
int loops = 0;
int transicion = 0;

// SetPoint

int set_point_red = 60;
int set_point_green = 584;

// Angulos

int angulo_centro = 90;
int angulo_min = 70;
int angulo_max = 115;
int angulo_servo = angulo_centro;

// Kp
float kp = 0.007f;
float kp_red = 0.4f;
float kp_green = 0.01f;

// Kd
float kd = 0.02f;
float kd_green = 0.0;
float kd_red = 0.15;

// Previous errors
float previous_error = 0.0;
float previous_error_green = 0.0;
float previous_error_red = 0.0;

// Variables de cronómetro
double current_timer = 0.0;
double stop_timer = 0.0;

// Booleans
bool stop_triggered = false; // Bandera para activar el cronómetro de la vuelta 12 una sola vez
bool CDloops = false;

// PID
float absolute_error;

// --- VARIABLES DE HISTÉRESIS PARA OBSTÁCULOS (AGREGAR ESTO) ---
bool modo_esquive_activo = false;
int frames_sin_obstaculo = 0;
int frames_en_esquive = 0;
const int FRAMES_ESPERA_SALIDA = 8;   // ~0.3 a 0.4 segundos de "memoria"
const int FRAMES_MIN_ESQUIVE = 8;     // Frames mínimos que debe durar el esquive
bool ultimo_obstaculo_fue_rojo = false; // Para recordar el color si parpadea


// Main code

int main() {
    std::cout << "=== PRUEBA DEL CONSTRUCTOR ===" << std::endl;
    std::cout << "A punto de crear VisionController..." << std::endl;
    std::cout << "VisionController creado exitosamente." << std::endl;
    
    const std::vector<std::vector<int>> range_black = {{0, 0, 100}, {85, 255, 255}};
    const std::vector<std::vector<int>> range_blue  = {{0, 0, 0}, {180, 180, 110}};
    const std::vector<std::vector<int>> range_orange = {{100, 100, 155}, {190, 170, 255}};
    const std::vector<std::vector<int>> range_red = {{0, 170, 145}, {145, 255, 180}};
    const std::vector<std::vector<int>> range_green = {{90, 75, 155}, {255, 125, 180}};
    const std::vector<std::vector<int>> range_purple = {{34, 161, 87}, {255, 255, 127}};

    // Inicializar el motor DMA de pigpio
    if (gpioInitialise() < 0) {
        std::cerr << "❌ Error inicializando pigpio. Ejecuta con sudo.\n";
        return -1;
    }

    // Uso del gestor de señales nativo de pigpio para evitar conflictos de hilos
    gpioSetSignalFunc(SIGINT, capturar_ctrl_c);

    // Configurar pines como salidas
    gpioSetMode(SERVO_PIN, PI_OUTPUT);
    gpioSetMode(MOTOR_IN1, PI_OUTPUT);
    gpioSetMode(MOTOR_IN2, PI_OUTPUT);

    // CONFIGURACIÓN DEL BOTÓN
    gpioSetMode(BUTTON_PIN, PI_INPUT);
    gpioSetPullUpDown(BUTTON_PIN, PI_PUD_UP); // Activa resistencia pull-up interna

    // Posición inicial segura
    mover_motor(Sentido::PARAR, 0);
    mover_servo(90);

    std::cout << "\n==================================================\n";
    std::cout << "🟢 HARDWARE LISTO.\n";
    std::cout << "🔘 ESPERANDO PULSACIÓN DEL BOTÓN EN GPIO " << BUTTON_PIN << "...\n";
    std::cout << "==================================================\n\n";

    // BUCLE DE ESPERA DEL BOTÓN
    while (ejecutando && gpioRead(BUTTON_PIN) == PI_LOW) { // ACTIVACION/DESACTIVACION 
        std::this_thread::sleep_for(std::chrono::milliseconds(50));
    }

    // Si se presionó Ctrl+C durante la espera, salir limpiamente
    if (!ejecutando) {
        gpioTerminate();
        return 0;
    }
    
    // Main code
    while (ejecutando) {
        vision.receive_image();
        const cv::Mat& current_frame = vision.get_frame();

        if (current_frame.empty()) {
            std::cerr << "No se pudo obtener imagen" << std::endl;
            continue;
        }

        // Cronometro

        auto now = std::chrono::steady_clock::now();

        if (CDloops) {
            std::chrono::duration<double> transcurrido = now - LastTimeDetected;

            if (transcurrido.count() >= 1.0) {
                CDloops = false;
            }
        }

        auto res_left = get_color_area(roi1, current_frame, range_black);
        left_blk = !res_left.empty() ? res_left[0].first : 0;

        auto res_right = get_color_area(roi2, current_frame, range_black);
        right_blk = !res_right.empty() ? res_right[0].first : 0;

        auto res_central = get_color_area(roi3, current_frame, range_black);
        central_blk = !res_central.empty() ? res_central[0].first : 0;

        auto res_blue = get_color_area(roi4, current_frame, range_blue);
        down_blue = !res_blue.empty() ? res_blue[0].first : 0;

        auto res_orange = get_color_area(roi4, current_frame, range_orange);
        down_orange = res_orange[0].first;

        auto res_blkt = get_color_area(roi5, current_frame, range_black);
        central_blkt = !res_blkt.empty() ? res_blkt[0].first : 0;

        red_data = get_color_area(roi6, current_frame, range_red);
        green_data = get_color_area(roi6, current_frame, range_green);

        central_red_area = !red_data.empty() ? red_data[0].first : 0;
        central_red_X    = red_data.size() > 1 ? red_data[1].first : 0;

        central_green_area = !green_data.empty() ? green_data[0].first : 0;
        central_green_X    = green_data.size() > 1 ? green_data[1].first : 0;
        
        // --- VARIABLES DE HISTÉRESIS PARA OBSTÁCULOS --- bool modo_esquive_activo = false; int frames_sin_obstaculo = 0; int frames_en_esquive = 0; const int FRAMES_ESPERA_SALIDA = 8;   // ~0.3 a 0.4 segundos de "memoria" const int FRAMES_MIN_ESQUIVE = 5;     // Frames mínimos que debe durar el esquive bool ultimo_obstaculo_fue_rojo = false; // Para recordar el color si parpadea
        bool hay_obstaculo_rojo = (central_red_area > 900 && central_red_area > central_green_area);
        bool hay_obstaculo_verde = (central_green_area > 2200 && central_green_area > central_red_area);
        bool hay_obstaculo = hay_obstaculo_rojo || hay_obstaculo_verde;

        if (hay_obstaculo) {
            frames_sin_obstaculo = 0;                  // Reset: lo estamos viendo
            modo_esquive_activo = true;
            frames_en_esquive++;
            
            // Guardamos en memoria qué color vimos (evita que cambie a mitad del esquive)
            if (hay_obstaculo_rojo) {
                ultimo_obstaculo_fue_rojo = true;
            } else {
                ultimo_obstaculo_fue_rojo = false;
            }
        } else {
            frames_sin_obstaculo++;                    // No lo vemos, sumamos 1 frame
        }

        // ¿Ya podemos salir del modo esquive?
        if (frames_sin_obstaculo >= FRAMES_ESPERA_SALIDA) {
            modo_esquive_activo = false;
            frames_en_esquive = 0; // Reiniciamos para la próxima vez
        }

        /*vision.draw_roi(roi1, cv::Scalar(255, 0, 0));
        vision.draw_roi(roi2, cv::Scalar(255, 0, 0));*/
        /*vision.draw_roi(roi3, cv::Scalar(255, 255, 0));
        vision.draw_roi(roi4, cv::Scalar(255, 0, 255));
        vision.draw_roi(roi5, cv::Scalar(255, 0, 0));*/

        // Texto con información
        std::cout//<< "Blue Max Area: "   << down_blue   << "\n"
                 //<< "Orange Max Area: " << down_orange << "\n"
                 << "Red Area: " << central_red_area << " | X: " << central_red_X <<  "\n"
                 << "Green Area: " << central_green_area << " | X: " << central_green_X << "\n"
                 //<< "Transicion " << transicion << "\n"
                 << "Error abs: " << absolute_error << "\n"
                 << "Previous Error: " << previous_error << "\n"
                 << "BlackC Max Area: " << central_blk << "\n"
                 << "BlackL Max Area: " << left_blk << "\n"
                 << "BlackR Max Area: " << right_blk << std::endl;


        // =========================================================================
        // LÓGICA DE ESQUIVE CON PESO POR PROXIMIDAD (ÁREA)
        // =========================================================================
        if (modo_esquive_activo) {
            
            if (ultimo_obstaculo_fue_rojo) {
                float error_red = central_red_X - set_point_red;
                float derivative_red = error_red - previous_error_red;
                previous_error_red = error_red;
                
                // 1. CALCULAR PESO POR PROXIMIDAD (ROJO)
                // Restamos el umbral de detección (900). Si está lejos, area_util es 0.
                float area_util = std::max(0.0f, (float)central_red_area - 900.0f);
                // Dividimos por 2500. Cuando el área sea 3400, el peso será 1.0 (100% de corrección)
                float peso = std::min(1.0f, area_util / 2500.0f);
                
                // 2. APLICAR EL PESO A LA CORRECCIÓN TOTAL
                float correccion_der = peso * ((kp_red * error_red) + (kd_red * derivative_red));
                float angulo_red = angulo_centro + correccion_der;
    
                if (angulo_red < 80) angulo_red = 80;
                else if (angulo_red > 110) angulo_red = 110;
                
                // 3. VELOCIDAD ADAPTATIVA: Frena suavemente mientras más cerca esté el obstáculo
                int velocidad = 200 - (int)(peso * 60); // Rango: 200 (lejos) a 140 (muy cerca)
                
                mover_servo((int)angulo_red);
                mover_motor(Sentido::ADELANTE, velocidad); 
                std::cout << "🔴 ROJO | Area: " << central_red_area << " | Peso: " << peso << " | Ang: " << (int)angulo_red << " | Vel: " << velocidad << "\n";
    
            } else {
                float error_green = central_green_X - set_point_green;
                float derivative_green = error_green - previous_error_green;
                previous_error_green = error_green;
                
                // 1. CALCULAR PESO POR PROXIMIDAD (VERDE)
                float area_util = std::max(0.0f, (float)central_green_area - 2200.0f);
                float peso = std::min(1.0f, area_util / 2500.0f);
                
                // 2. APLICAR EL PESO A LA CORRECCIÓN TOTAL
                float correccion_izq = peso * ((kp_green * error_green) + (kd_green * derivative_green));
                float angulo_green = angulo_centro + correccion_izq;
    
                if (angulo_green < 80) angulo_green = 80;
                else if (angulo_green > 110) angulo_green = 110;
                
                // 3. VELOCIDAD ADAPTATIVA
                int velocidad = 200 - (int)(peso * 60);
                
                mover_servo((int)angulo_green);
                mover_motor(Sentido::ADELANTE, velocidad); 
                std::cout << "🟢 VERDE | Area: " << central_green_area << " | Peso: " << peso << " | Ang: " << (int)angulo_green << " | Vel: " << velocidad << "\n";
            }
        } else {
            // --- LÓGICA DE PARED NEGRA (NORMAL) ---
            mover_motor(Sentido::ADELANTE, 200);
            float error = left_blk - right_blk;
            float derivative = error - previous_error;
            previous_error = error;
            float correccion = (kp * error) + (kd * derivative);
            float angulo = 90 + correccion;
            absolute_error = std::abs(error);
                
            if (angulo < 80) {
                angulo = 80;
            } else if (angulo > 110) {
                angulo = 110;
            }
                
            mover_servo((int)angulo);   
        }
        
        std::cout << "Frames sin obstaculo: " << frames_sin_obstaculo << " | Loops: " << loops << std::endl;
        std::cout << loops << std::endl;

        /*if (down_orange > 100 && turning_direction == 2 && !CDloops) {
            loops++;
            LastTimeDetected = now;
            CDloops = true;
        }

        if (down_blue > 100 && turning_direction == 1 && !CDloops) {
            loops++;
            LastTimeDetected = now;
            CDloops = true;
        }

        // PARADA 12 VUELTAS
        if (loops == 12 && !stop_triggered) {
            stop_timer = current_timer;
            stop_triggered = true;
            std::cout << "🏁 ¡Vuelta 12 alcanzada!" << std::endl;
        }
        
        if (stop_triggered) {
            if (current_timer - stop_timer >= 4.0) {
                break;
            }
        }*/
    }

    // APAGADO SEGURO GARANTIZADO
    std::cout << "\n[!] Interrupción detectada. Abortando y limpiando recursos...\n";
    std::cout << "Apagando motor, cortando pulso del servo y liberando memoria...\n";
    
    mover_motor(Sentido::PARAR, 0); 
    gpioServo(SERVO_PIN, 0);     
    gpioTerminate();             

    std::cout << "✅ Robot detenido y recursos liberados correctamente.\n";
    return 0;
}

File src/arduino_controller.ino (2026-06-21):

#include "MeMegaPi.h"
#include <Adafruit_MPU6050.h>
#include <Adafruit_Sensor.h>
#include <Wire.h>
#include "Ultrasonic.h"
#include "Adafruit_VL53L0X.h"

// --- Constantes del Sistema ---
#define SERVO_CENTER    90
#define LEFT            0
#define RIGHT           180
#define SERIAL_BAUD     115200
#define SENSOR_TIMEOUT  25000

// Pines de Hardware Fijos
#define BUTTON           A9
#define pinServo         A7
#define trig_front       A15
#define echo_front       A14
#define trig_left        29
#define echo_left        39
#define trig_right       A11
#define echo_right       A10
#define centro           90

// --- Configuración Láser VL53L0X ---
const int XSHUT_PIN1 = 4;
const int XSHUT_PIN2 = 5;

const int LOX1_ADDRESS = 0x30; // Sensor ToF 1
const int LOX2_ADDRESS = 0x29; // Sensor ToF 2

// Instancias de Sensores
Ultrasonic sensorF(trig_front, echo_front);
Ultrasonic sensorL(trig_left, echo_left);
Ultrasonic sensorD(trig_right, echo_right);

Adafruit_VL53L0X lox1 = Adafruit_VL53L0X();
Adafruit_VL53L0X lox2 = Adafruit_VL53L0X();

class Carro {
  private:
    MeMegaPiDCMotor motorTraccion;
    Servo servoDireccion;
    Adafruit_MPU6050 mpu;
    
  public:
    // Motor conectado al Puerto 4B de la MegaPi
    Carro() : motorTraccion(PORT4B) {}

    void inicializar() {
      // Configuración del botón (Pull-up interna)
      pinMode(BUTTON, INPUT_PULLUP);

      // Configuración del Servo
      servoDireccion.attach(pinServo);
      servoDireccion.write(centro);
      
      // --- PASO 1: Apagar ambos sensores VL53L0X ---
      pinMode(XSHUT_PIN1, OUTPUT);
      pinMode(XSHUT_PIN2, OUTPUT);
      digitalWrite(XSHUT_PIN1, LOW);
      digitalWrite(XSHUT_PIN2, LOW);
      delay(100); 

      // --- PASO 2: Encender e iniciar SENSOR ToF 1 ---
      pinMode(XSHUT_PIN1, INPUT); // Pone en modo flotante para encender
      delay(100); 
      if (!lox1.begin(LOX1_ADDRESS)) {
        Serial.println("System: VL53L0X - Sensor 1 ERROR");
        while (1);
      }
      delay(10);

      // --- PASO 3: Encender e iniciar SENSOR ToF 2 ---
      pinMode(XSHUT_PIN2, INPUT); 
      delay(100);  
      if (!lox2.begin(LOX2_ADDRESS)) {
        Serial.println("System: VL53L0X - Sensor 2 ERROR");
        while (1);
      }

      Serial.println("System: Hardware and VL53L0X Initialized");
    }

    // --- Lógica de Sensores ---
    bool botonPresionado() {
      return digitalRead(BUTTON) == LOW; 
    }

    long getDistanciaFront() { return sensorF.read(); }
    long getDistanciaLeft()  { return sensorL.read(); }
    long getDistanciaRight() { return sensorD.read(); }

    // Retorna la distancia en CM del VL53L0X número 1
    int getDistanciaLaser1() {
      VL53L0X_RangingMeasurementData_t measure;
      lox1.rangingTest(&measure, false);
      if (measure.RangeStatus != 4) {
        return measure.RangeMilliMeter / 10; // Conversión mm -> cm
      }
      return 255; // Fuera de rango o lectura inválida
    }

    // Retorna la distancia en CM del VL53L0X número 2
    int getDistanciaLaser2() {
      VL53L0X_RangingMeasurementData_t measure;
      lox2.rangingTest(&measure, false);
      if (measure.RangeStatus != 4) {
        return measure.RangeMilliMeter / 10; // Conversión mm -> cm
      }
      return 255; 
    }

    // --- Lógica de Movimiento ---
    void avanzar(byte velocidad) {
      motorTraccion.run(velocidad);
    }

    void retroceder(byte angulo, byte velocidad) {
      servoDireccion.write(centro);
      servoDireccion.write(angulo);
      motorTraccion.run(-velocidad);
    }

    void girarIzquierda(byte angulo, byte velocidad) {
      servoDireccion.write(angulo);
      motorTraccion.run(velocidad);
    }

    void girarDerecha(byte angulo, byte velocidad) {
      servoDireccion.write(angulo);
      motorTraccion.run(velocidad);
    }

    void detenerse() {
      motorTraccion.stop();
      servoDireccion.write(centro);
    }

    void girarCentro() {
      servoDireccion.write(centro);
    }
};

Carro miCarro;
unsigned long timerSensores = 0;

void setup() {
  Serial.begin(SERIAL_BAUD);
  miCarro.inicializar();
}

void loop() {
  // --- PARTE 1: Procesamiento de Comandos (Raspberry -> Arduino) ---
  if (Serial.available() >= 5) {
    byte header = Serial.read();
    if (header == 0xFF) {
      byte tipo   = Serial.read();
      byte accion = Serial.read();
      byte v1     = Serial.read(); 
      byte v2     = Serial.read(); 

      switch (accion) {
        case 1: miCarro.avanzar(v1); break;
        case 2: miCarro.retroceder(v1, v2); break;
        case 3: miCarro.girarIzquierda(v1, v2); break;
        case 4: miCarro.girarDerecha(v1, v2); break;
        case 5: miCarro.detenerse(); break;
        case 6: miCarro.girarCentro(); break;
        case 7: miCarro.inicializar(); break; 
        default: miCarro.detenerse(); break;
      }
    }
  }

  // --- PARTE 2: Telemetría (Arduino -> Raspberry) cada 100ms ---
  if (millis() - timerSensores > 100) {
    int d_front  = (int)miCarro.getDistanciaFront();
    int d_left   = (int)miCarro.getDistanciaLeft();
    
    // NOTA: Como agregaste dos sensores láser, ajusté estas variables para enviarlos.
    int d_laser1 = miCarro.getDistanciaLaser1(); // Sensor ToF Dirección 0x30
    int d_laser2 = miCarro.getDistanciaLaser2(); // Sensor ToF Dirección 0x29
    
    byte estadoBoton = miCarro.botonPresionado() ? 1 : 0;
    
    // ESTRUCTURA DEL PAQUETE MANTENIENDO LOS 8 BYTES
    Serial.write(0xAA);                        // Byte 0: Header de inicio
    Serial.write(constrain(d_front, 0, 255));  // Byte 1: Distancia Frontal (Ultrasónico)
    Serial.write(constrain(d_left, 0, 255));   // Byte 2: Distancia Izquierda (Ultrasónico)
    Serial.write(constrain(d_laser1, 0, 255)); // Byte 3: Reemplaza d_right -> AHORA ES LÁSER ToF 1
    Serial.write(constrain(d_laser2, 0, 255)); // Byte 4: Reemplaza d_rightf -> AHORA ES LÁSER ToF 2
    Serial.write(estadoBoton);                 // Byte 5: Estado del Botón (0 o 1)
    Serial.write(0x00);                        // Byte 6: Relleno (Padding)
    Serial.write(0x00);                        // Byte 7: Relleno (Padding)
    
    timerSensores = millis();
  }
}

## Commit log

2026-06-21 Adjust PID parameters for obstacle avoidance and update speed settings
    [HardCodeTest.py, Obstacle_challenge.py]
2026-06-21 Refactor distance sensor logic and improve error handling
    [mega_pi_controller.py]
2026-06-21 Refactor distance sensors and telemetry mapping
    Updated distance sensor variables and telemetry mapping to include new laser sensors.
2026-06-21 Integrate VL53L0X sensors and update telemetry
    Added support for VL53L0X laser distance sensors and updated telemetry structure.
2026-06-21 Integrate ToF sensors for distance measurement
2026-06-22 Fix typo and update distance unpacking in openchallenge2.py
    Corrected typo in emergency brake configuration comment and updated distance unpacking.
    [openchallenge2.py]
2026-06-22 Fix unpacking of distances in obstacle avoidance
    [Obstacle_challenge.py]
2026-06-24 Refactor obstacle processing logic and enhance track type detection
2026-07-03 Implement anti-stuck detection and enhance image handling
    Added anti-stuck detection algorithm and improved image processing.
    [vision_controller.py]
2026-07-03 Implement visual stall detection and handbrake logic
    Added handbrake trigger for visual stall detection and reset stuck timer in various states.
    [test.py]
2026-07-04 Adjust minimum collision distance and static time threshold for improved control
    [test.py, vision_controller.py]
2026-07-05 Enhance cornering logic and add stall detection
    Restructured state machine for corner maneuver and added stall detection.
    [prueba_esquina.py]
2026-08-02 Refactor stall detection logic and adjust cornering conditions for improved navigation
    [PUSL.py, mega_pi_controller.py, prueba_esquina1.py]
2026-08-15 Refactor PUSL.py to integrate MegaPiController and enhance obstacle detection logic; add non-blocking timer functionality in Timer.py
2026-08-22 Fixing vision controller's script
    [app.cpp]
2026-08-22 Revise team section and add cost comparison
    Updated team member details and added cost comparison for prototype components.
2026-08-22 Fix link formatting for URGENEX battery in README
2026-08-22 Revise component descriptions and images in README
    Updated descriptions and images for various components including Raspberry Pi models, batteries, and motors.
2026-08-22 Update servo model and total price in README
    Replaced SG90 servo with MG90S in the product list and updated total price.
2026-08-22 Add initial versions of corner detection and obstacle avoidance scripts
    - Created `prueba_esquina.py` for corner detection with PID navigation and obstacle avoidance.
    - Developed `prueba_esquina1.py` with enhanced anti-rollover control and obstacle detection logic.
    - Introduced `test.py` for testing the vision and navigation functionalities with additional safety measures.
    - Implemented `vision_controller.py` to manage image acquisition, processing, and contour detection for the robot's vision system.
    [HardCodeTest.py, Obstacle_challenge.py, PID_class.py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]
2026-08-22 Update Gikfun Touch Switch image in README
2026-08-22 Gestor de komrad actualizado
2026-08-22 Update components and power consumption details
2026-08-24 Update camera handling and color mask configuration for improved compatibility
2026-08-27 Add installation script for OpenCV, GStreamer, and GPIO on Raspberry Pi
2026-08-31 Revise sensor distribution details in README
    Updated sensor distribution descriptions and images in the README.
2026-08-31 Add files via upload
    new STL files
    [Chasis Ing_07.stl, ing BAT SOP.stl, ing SERVO ARM.stl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]
2026-08-31 Update README with 3D printed components details
2026-08-31 Revise power architecture and energy budget in README
    Updated power architecture and energy budget details in README.md, transitioning from a dual battery system to a centralized architecture with a single URGENEX 2S LiPo battery. Adjusted consumption f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
2026-09-01 Update README with new component descriptions and images
    Added new cases and components to the README, including Battery Case Holder, Rim, Motor DC Case, and others with detailed descriptions and images.
2026-09-01 Actualizar descripciones de sensores en README
    Se actualizó la descripción del sensor ToF VL53L0X para incluir su función en la detección de paredes en los dos primeros retos. Se eliminaron detalles redundantes sobre el arreglo de sensores láser.
2026-09-01 Update motor specification from RS380 to N20
2026-09-02 Fix pipeline height in app.cpp
    [app.cpp]
2026-09-02 Add newline at end of motorsgpiotest.cpp
    Fix missing newline at end of file
2026-09-02 Modify image dimensions and frame processing
    Adjusted image height from 480 to 370 and added vertical flip for frame processing.
2026-09-02 Change window size and camera capture settings
    Updated window dimensions and camera capture method.
2026-09-04 Enhance vision controller with GPIO and color detection
    Added GPIO control for servo and motor, implemented color detection logic, and improved signal handling for safe shutdown.
2026-09-07 Revise README with new 3D printed components
    Updated the README to include new 3D printed components and their descriptions, enhancing clarity on design and engineering purposes.
2026-09-08 new files
    [Chasis Ing_01.stl, Chasis Ing_02.stl, Chasis Ing_03.stl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]
2026-09-08 new 3d files
    [Ing PIN WHEEL.stl, Ing SOP NEW EJE .stl, Ing SOP TOP.stl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]
2026-09-08 Update README with Ackermann system and 3D assembly details
    Added images and sections for Ackermann system models and 3D component assembly.
2026-09-08 Update Camera Case image and description in README
2026-09-08 Revise Camera Case description in README
    Updated the description of the Camera Case to reflect design changes and insights from prototype testing.
2026-09-08 Remove cable connection problems section from README
    Removed section about cable connection issues and solutions.
2026-09-08 Revise flowchart section in README
    Updated flowchart images and adjusted formatting for clarity.
2026-09-08 Update README with 3D sample image and printer info
    Added a 3D sample image to the README and updated the text regarding the printer.
2026-09-08 Add button functionality and improve code structure
2026-09-08 Refactor interrupt handling and button wait logic
    Refactor interrupt handling and button waiting loop for clarity. Update comments for better understanding.
2026-09-09 Update README with modified wheel test link
    Added a link for testing with the modified wheel.
2026-09-12 Fix formatting for DRV8833 Dual Motor Driver power specs
2026-09-13 Enhance README with installation and usage instructions
    Added detailed installation instructions for OpenCV and GPIO on Raspberry Pi, along with compilation and execution steps for C++ applications.
2026-09-13 Enhance PID control and implement obstacle avoidance
    Refactor PID control logic and add obstacle avoidance features.
    [app2.cpp]
2026-09-13 Update wiring diagram image in README
2026-09-13 Add image to README for wiring diagram
2026-09-13 Fix formatting in README.md for wiring diagram
2026-09-13 Update README to include flow diagrams
2026-09-14 Update README with rear-wheel drive demonstration
    Added a section for rear-wheel drive demonstration.
2026-09-14 Expand technical specifications and kinematic analysis
    Added detailed specifications for N20 motors and kinematic analysis of the vehicle's performance, including calculations for theoretical speed and interaction between rear traction and Ackermann stee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
2026-09-15 Add details about Creality Hi and K1 printers
2026-09-15 Update image dimensions for camera support file
